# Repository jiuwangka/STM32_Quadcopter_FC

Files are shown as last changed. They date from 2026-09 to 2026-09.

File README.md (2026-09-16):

# STM32 四轴飞行器飞控板 (4-Layer PCB)

基于开源四轴飞行器项目进行硬件方案设计，结合芯片数据手册重新设计飞控板硬件电路，完成原理图绘制、四层PCB设计及硬件调试。

## 我的工作

本人主要负责：

- 飞控板硬件方案设计与器件选型
- 基于芯片数据手册进行外围电路参数设计
- 原理图设计与25×50mm四层PCB设计
- 3.7V→5V→3.3V电源架构设计
- 4路MOSFET电机驱动电路设计
- PCB打样、焊接及硬件调试
- LTspice电机驱动瞬态仿真与电路优化

## 核心硬件架构

- **主控平台**：STM32F103T8U6，72MHz
- **姿态传感**：MPU6050 六轴传感器
- **无线通信**：GC2400-TC017 2.4GHz无线射频模组
- **电源架构**：FP6276BXR-G1 Boost DC-DC（1S锂电池升压至5V）+ TP2019-3.3 LDO（二次降压至3.3V）
- **电机驱动**：4路CJ2310 N-MOSFET驱动716空心杯电机
- **瞬态保护**：1N5819W肖特基续流二极管

## 四层PCB与SI/PI设计

1. **PCB叠层**：L1信号层 - L2连续GND平面 - L3电源层 - L4辅助走线与散热地。
2. **电源与回流设计**：L2采用连续GND平面，为高速及敏感信号提供连续低阻抗回流路径；L3对4路电机采用星型电源分配，减少公共供电路径上的压降及支路间干扰。
3. **射频设计**：GC2400-TC017板载天线区域进行全层铺铜挖空，降低PCB铜箔对2.4GHz射频性能的影响。
4. **瞬态仿真**：提供 `Motor_Drive_Simulation.asc`，通过LTspice分析PWM关断瞬态，加入1N5819W后将仿真中的约500V感应电压尖峰钳位至约4.45V。

## 仓库文件

- `Quadcopter_FC_Hardware_Portfolio_FINAL_V2.1.pdf`：12页硬件设计作品集
- `Gerber.zip`：PCB制造文件
- `BOM.xlsx`：物料清单
- `Pick Place for Quadcopter_FC.csv`：SMT贴装坐标文件
- `Motor_Drive_Simulation.asc`：LTspice电机驱动瞬态仿真
- `Source_Altium/`：Altium Designer工程源码

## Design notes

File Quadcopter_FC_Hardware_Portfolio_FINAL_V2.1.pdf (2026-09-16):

# STM32 Quadcopter Flight Controller (FC) V2.0

# STM32四轴飞行器飞控板系统设计

4-Layer PCB | 4.45V Simulation Result | Hardware Design Portfolio

# HARDWARE DESIGN PORTFOLIO

## PROJECT OVERVIEW · SHEET 01 / 13

系统硬件架构与电源树 / SYSTEM ARCHITECTURE & POWER TREE | 核心参数 / KEY SPECIFICATIONS

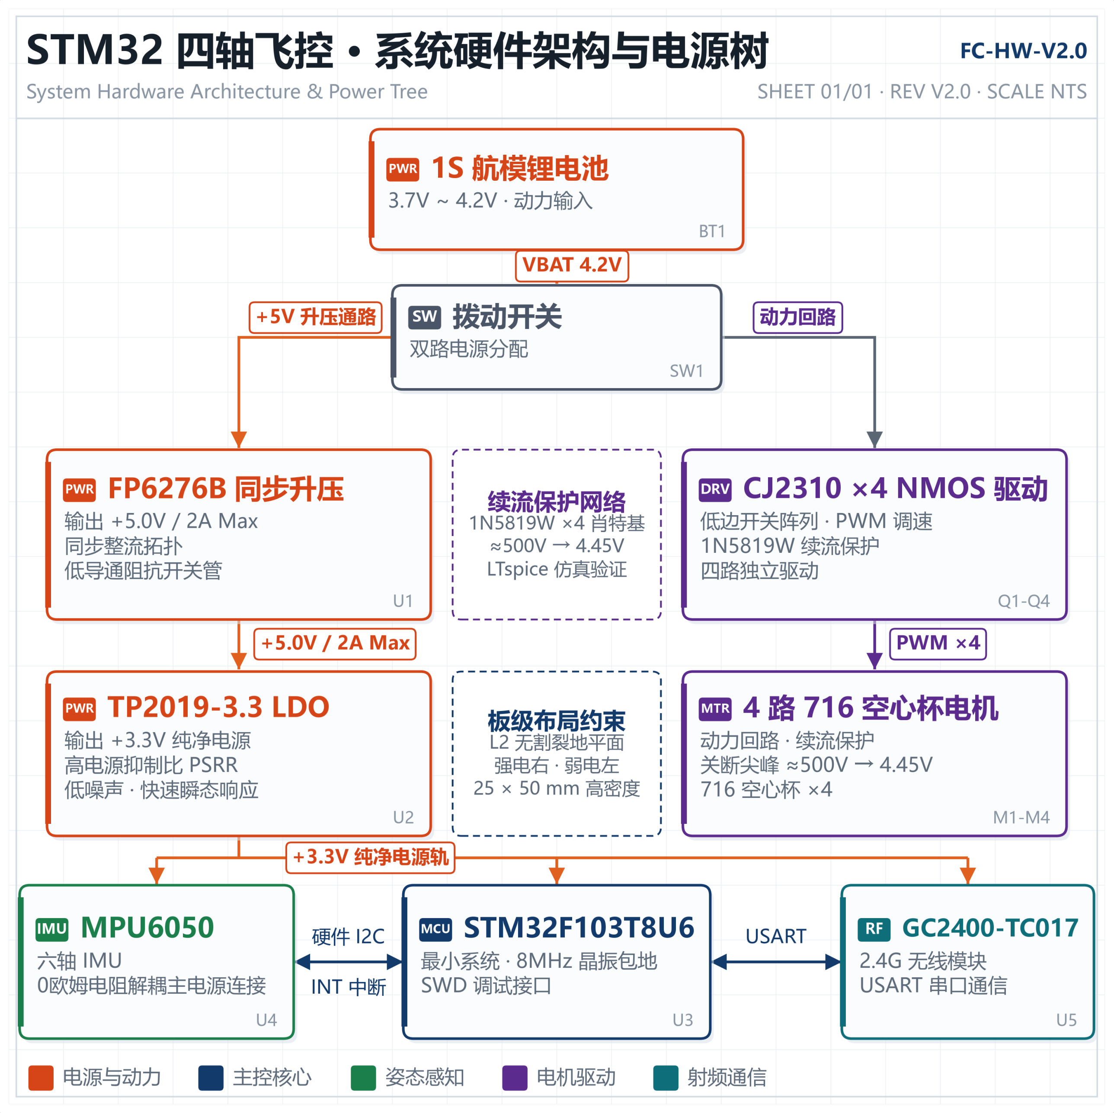
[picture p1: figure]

物理尺寸 | 25mm x 50mm（高密度微型航模规格）
PCB 叠层 | 4层板（Top信号 - L2完整地平面 - L3电源走线 -Bottom底层）
供电架构 | 1S 航模锂电输入 → FP6276B 同步升压 5V → TP2019 高 PSRR LDO 3.3V
动力保护 | 4路 CJ2310 NMOS + 1N5819W 肖特基续流二极管（LTspice 仿真钳位至 4.45V）
传感器与射频 | MPU6050 居中布局，GC2400-TC017 2.4G 板载无线射频模组

## 关键工程要点 / ENGINEERING HIGHLIGHTS

# 完整地回流

# L2 规划为无割裂完整地平面，为电机 PWM 动力回路提供低阻抗返回路径。

# 强弱电隔离

# 强电电机驱动阵列置于板卡右侧，远离左侧弱电 MCU 与 IMU。

# 瞬态钳位仿真

# 建立 716 空心杯电机等效模型，将约 500V 关断感应尖峰钳位至 4.45V。

## 信号链摘要 / SIGNAL CHAIN

## MPU6050

I2C

### STM32F103T8U6

### PWM

CJ2310 ×4

驱动

## 716 空心杯电机

## STM32 Quadcopter FC V2.0 · 微型四轴飞控板系统设计 · 硬件作品集

STM32 Quadcopter Flight Controller (FC) V2.0 | Hardware Portfolio | 01 - 3D Mechanical & Top Assembly View

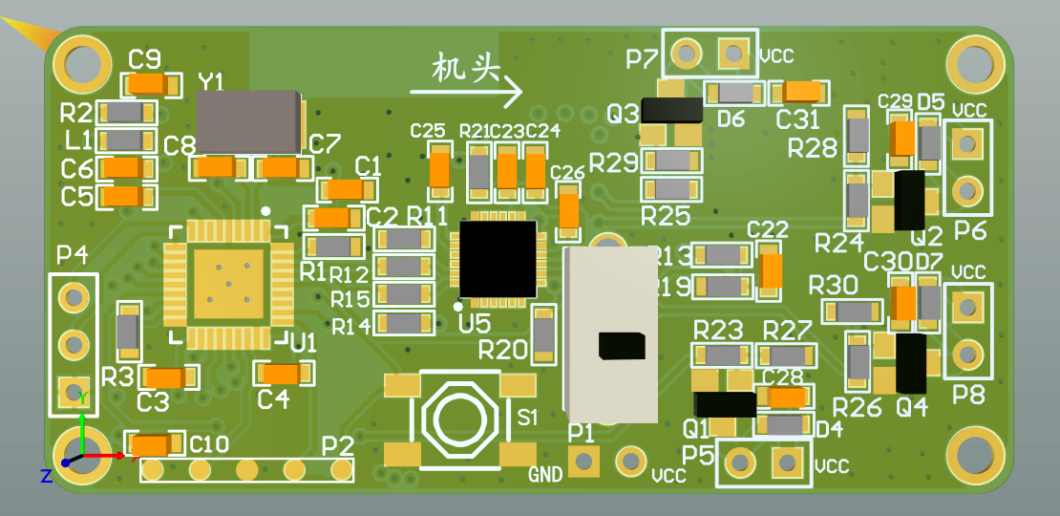
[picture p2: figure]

STM32 Quadcopter Flight Controller (FC) V2.0 | Hardware Portfolio | 01 - 3D Mechanical & Bottom Assembly View

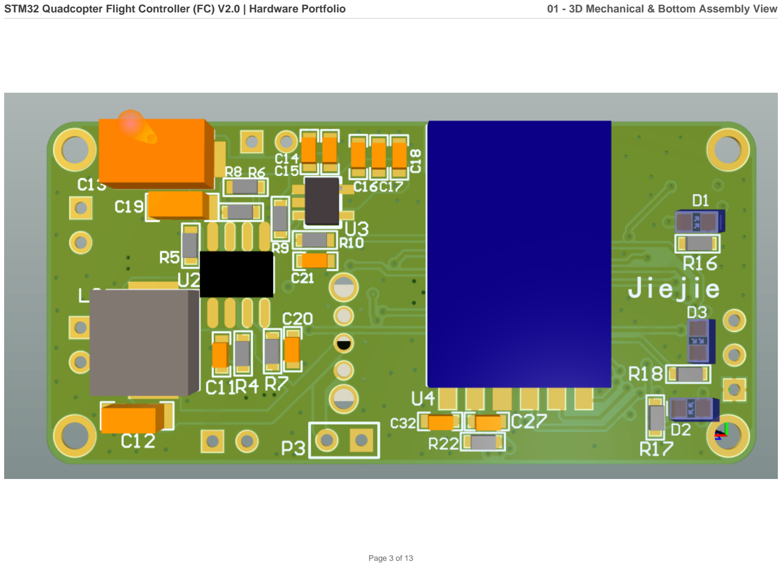
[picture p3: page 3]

## STM32电源区

## STM32功能区

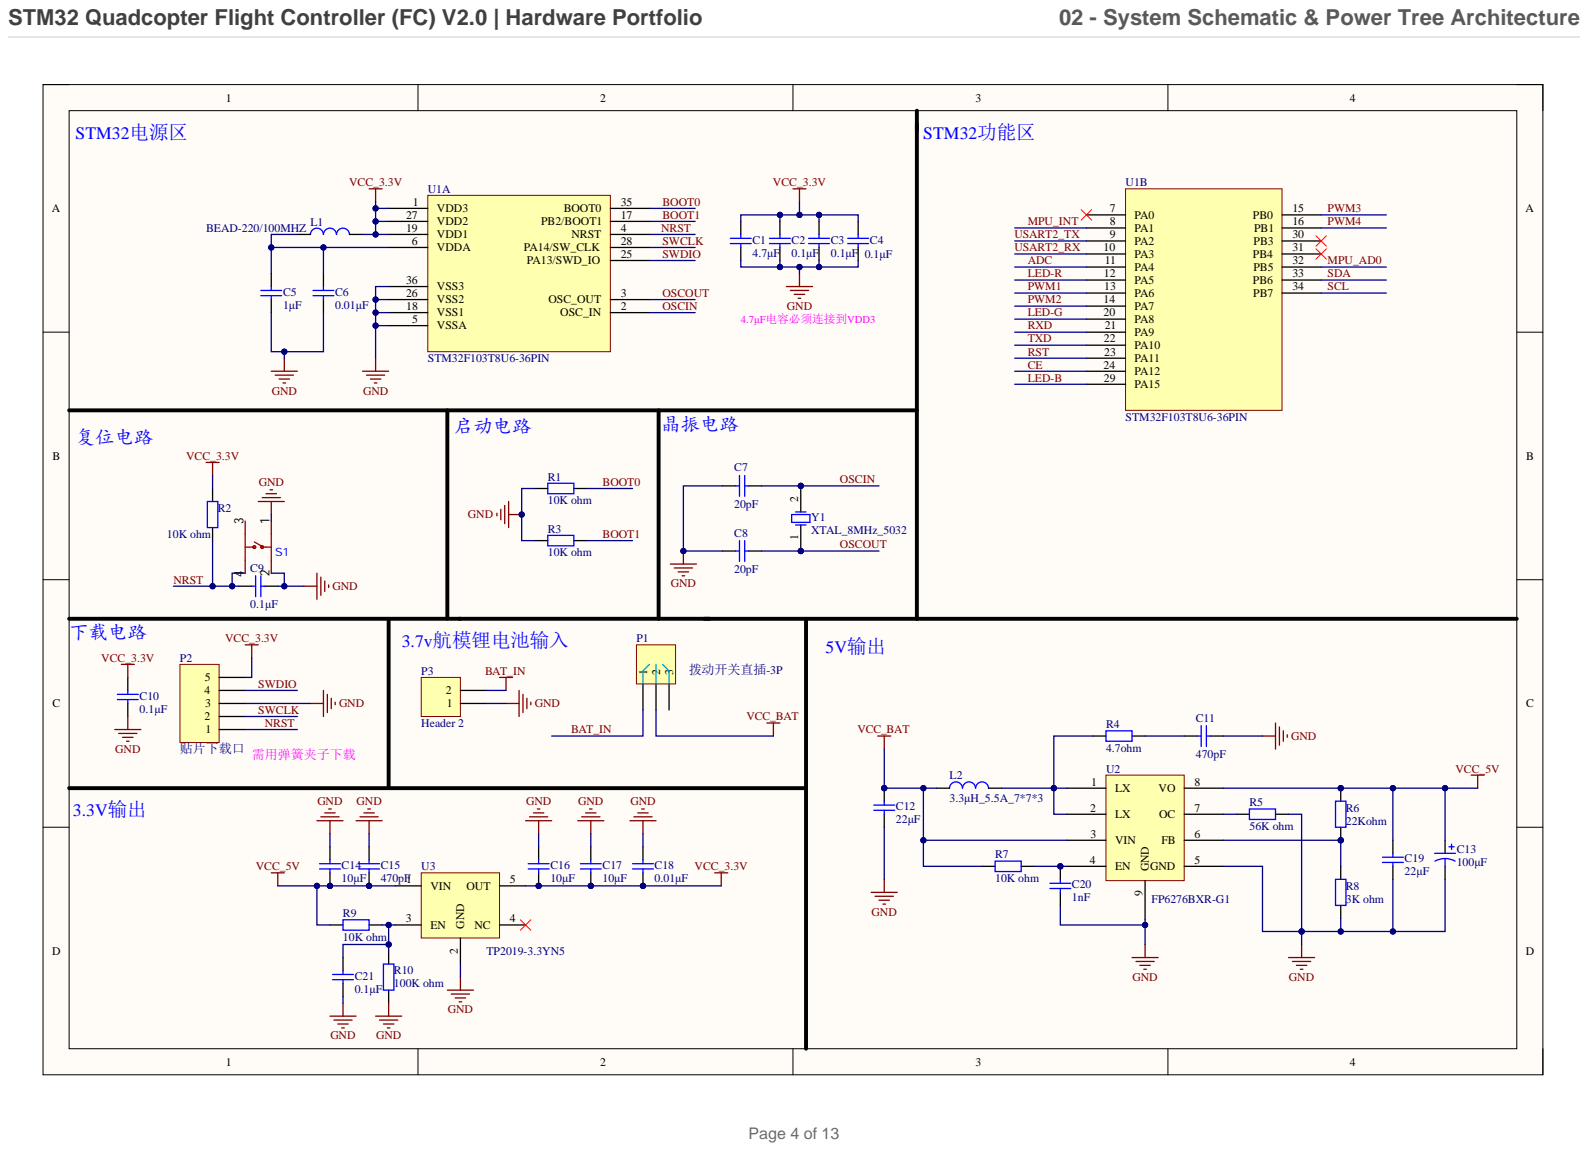
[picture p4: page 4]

# MPU6050

# 电量检测

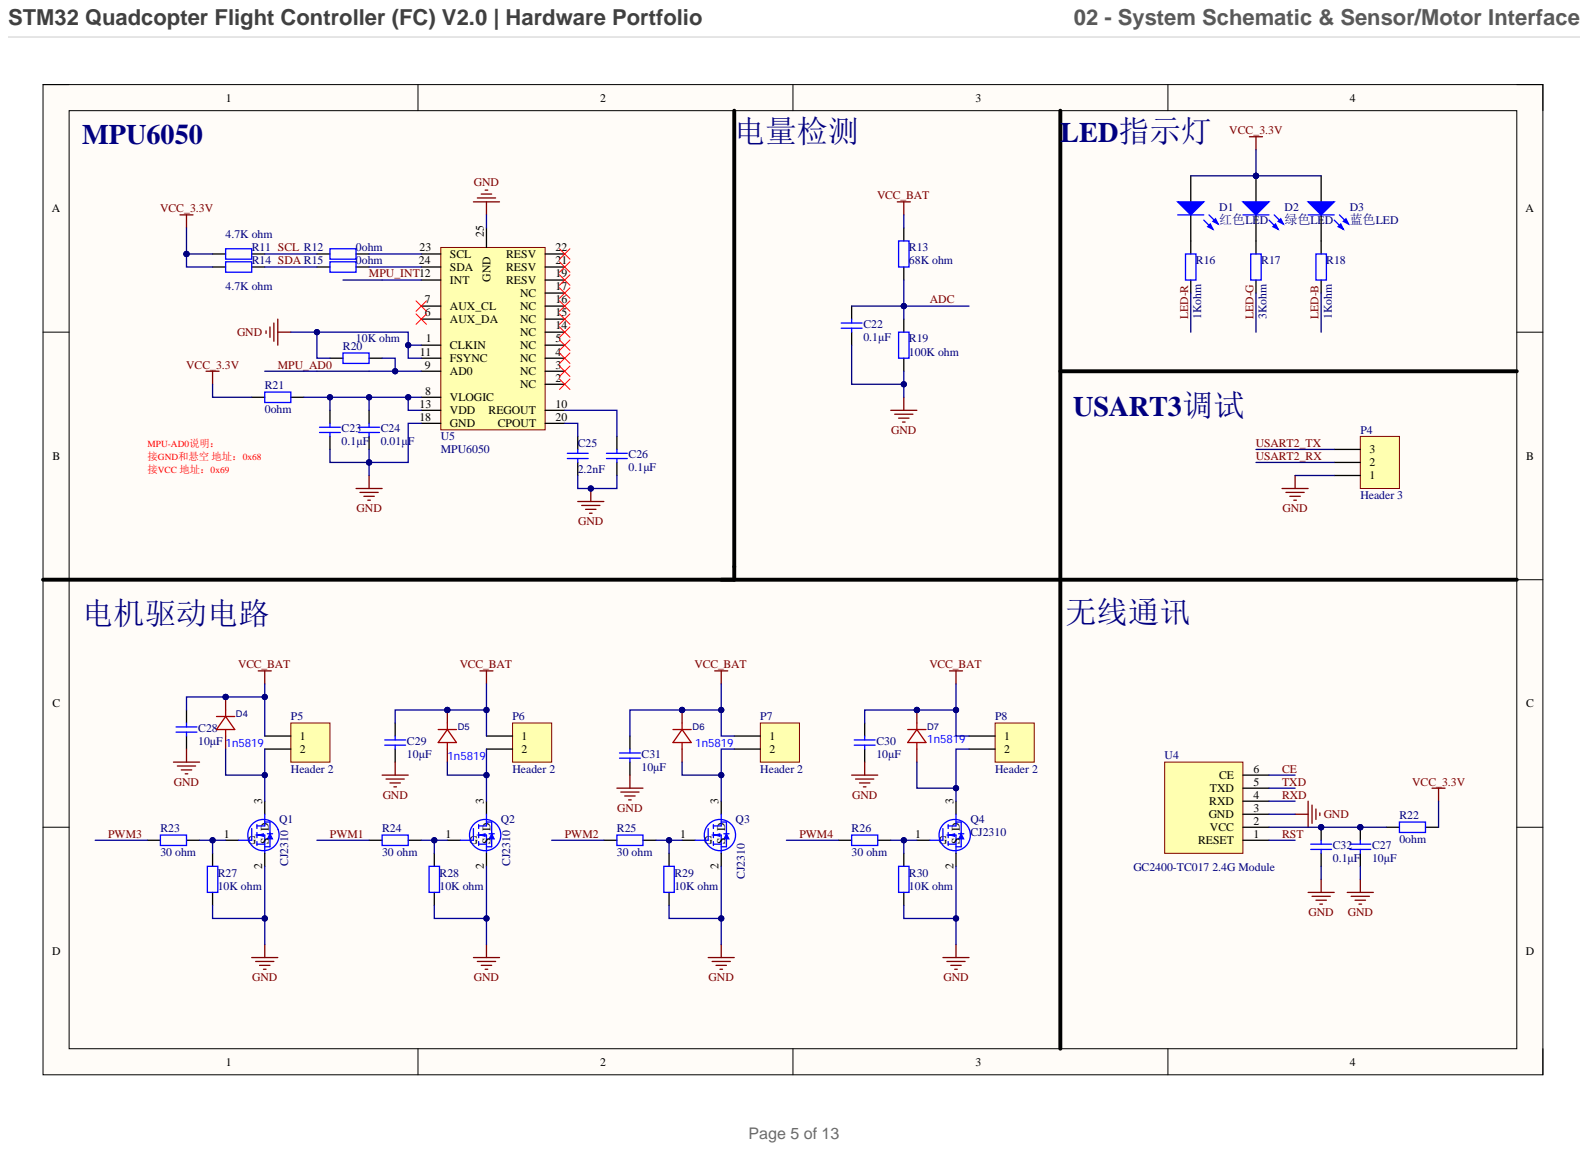
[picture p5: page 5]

STM32 Quadcopter Flight Controller (FC) V2.0 | Hardware Portfolio | 03 - PCB Component Placement & Top Assembly View

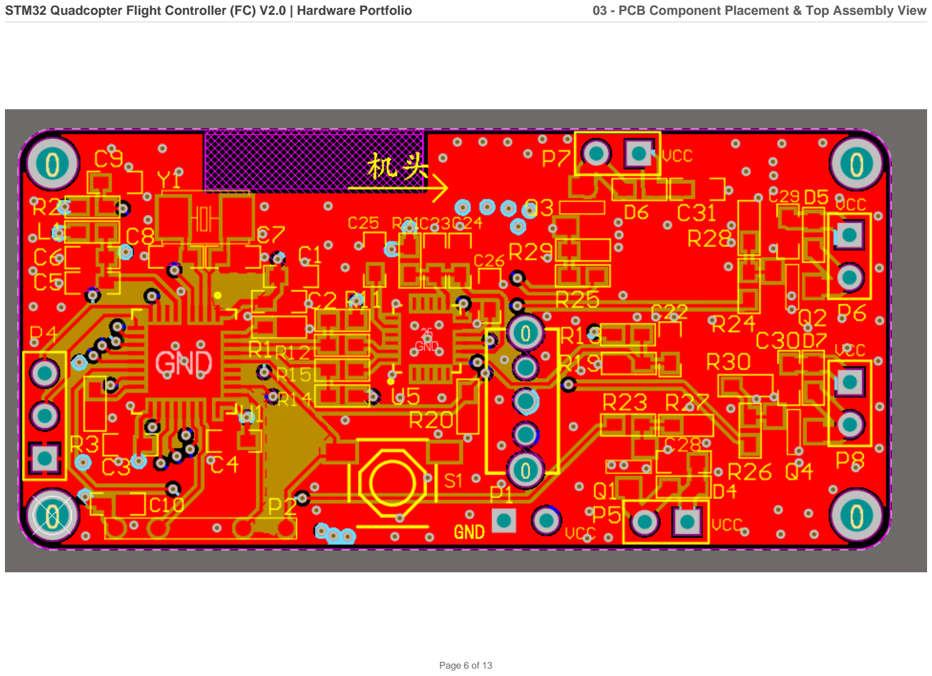
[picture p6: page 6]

STM32 Quadcopter Flight Controller (FC) V2.0 | Hardware Portfolio | 04 - Layer 1 (Top) High-Speed & Signal Routing

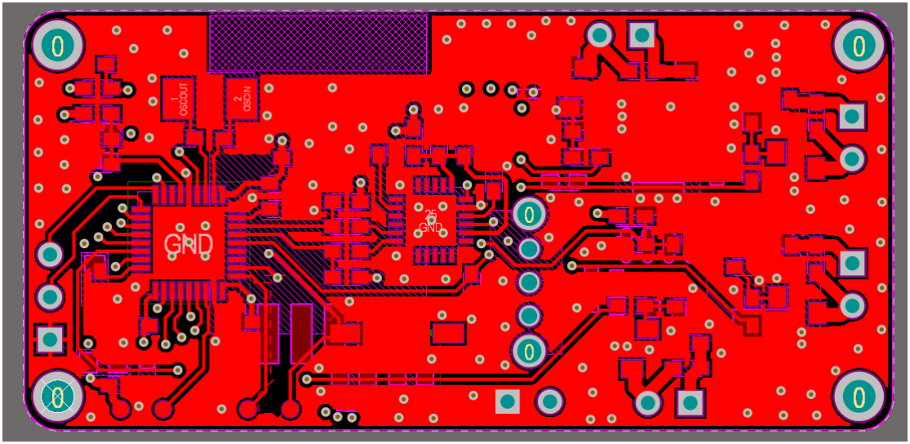
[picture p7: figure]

STM32 Quadcopter Flight Controller (FC) V2.0 | Hardware Portfolio | 04 - Layer 2 (GND) Continuous Ground Plane

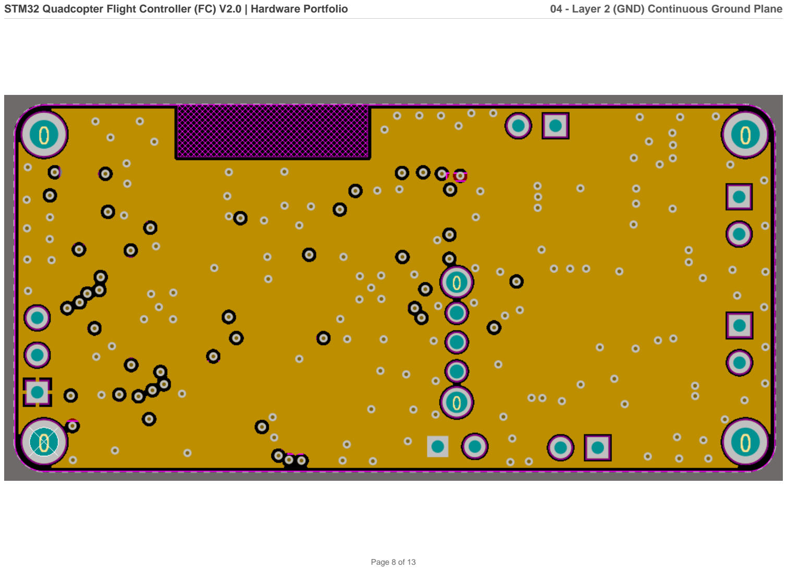
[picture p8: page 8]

STM32 Quadcopter Flight Controller (FC) V2.0 | Hardware Portfolio | 04 - Layer 3 (Power) Battery Power Routing

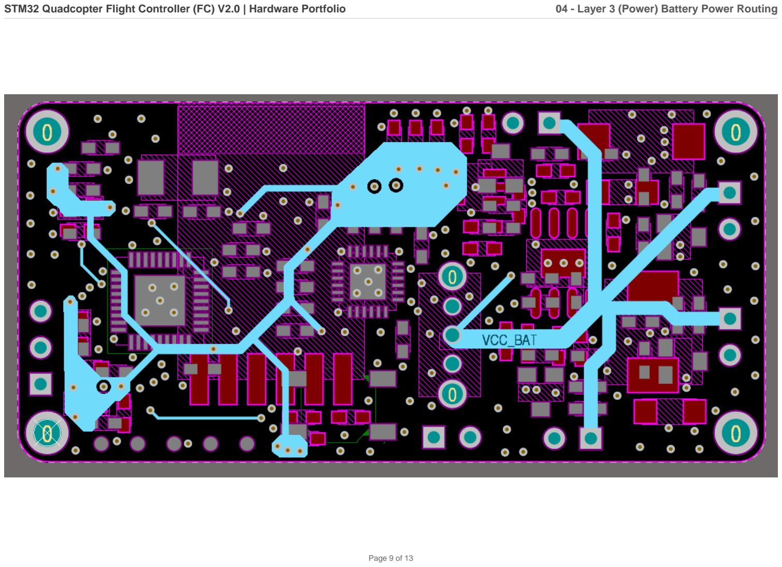
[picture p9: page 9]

STM32 Quadcopter Flight Controller (FC) V2.0 | Hardware Portfolio | 04 - Layer 4 (Bottom) Secondary Routing & Thermal Ground

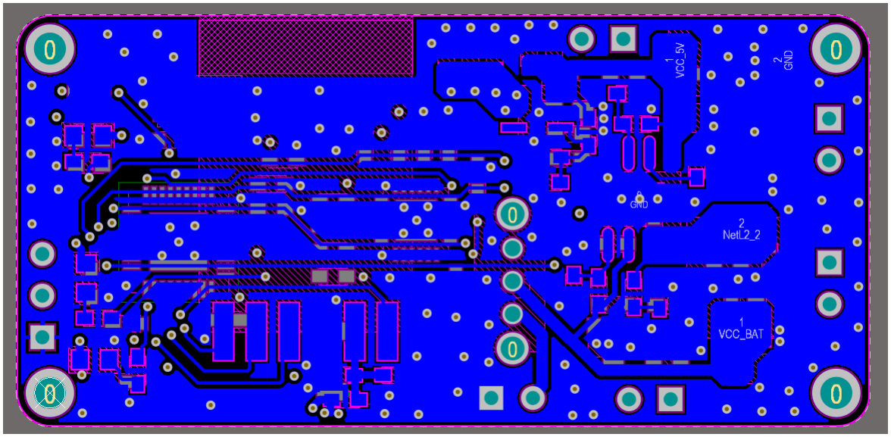
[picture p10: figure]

STM32 Quadcopter Flight Controller (FC) V2.0 | Hardware Portfolio | 05 - Power Rail Ripple Measurement (3.3V Vpp ~ 19.52mV)

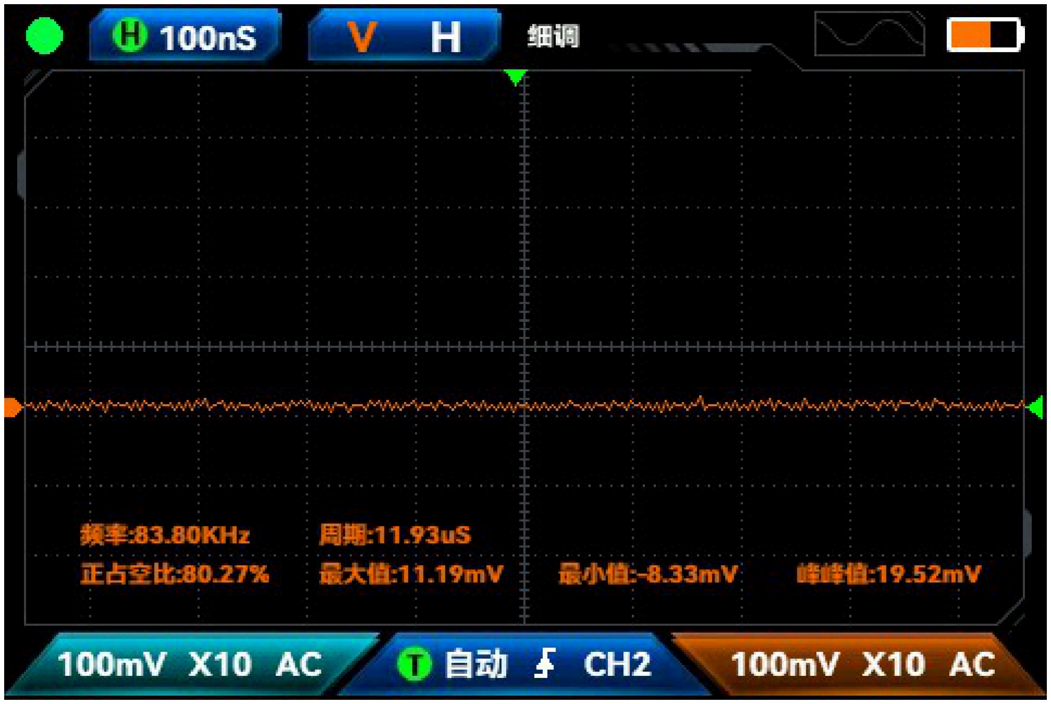
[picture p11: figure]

# 使用FNIRSI DS215H进行板级电源纹波测试，当前测试条件下测得3.3V节点Vpp约19.52mV。

STM32 Quadcopter Flight Controller (FC) V2.0 | Hardware Portfolio | 06 - Flyback Suppression Simulation (No Diode: ~500V Spike)

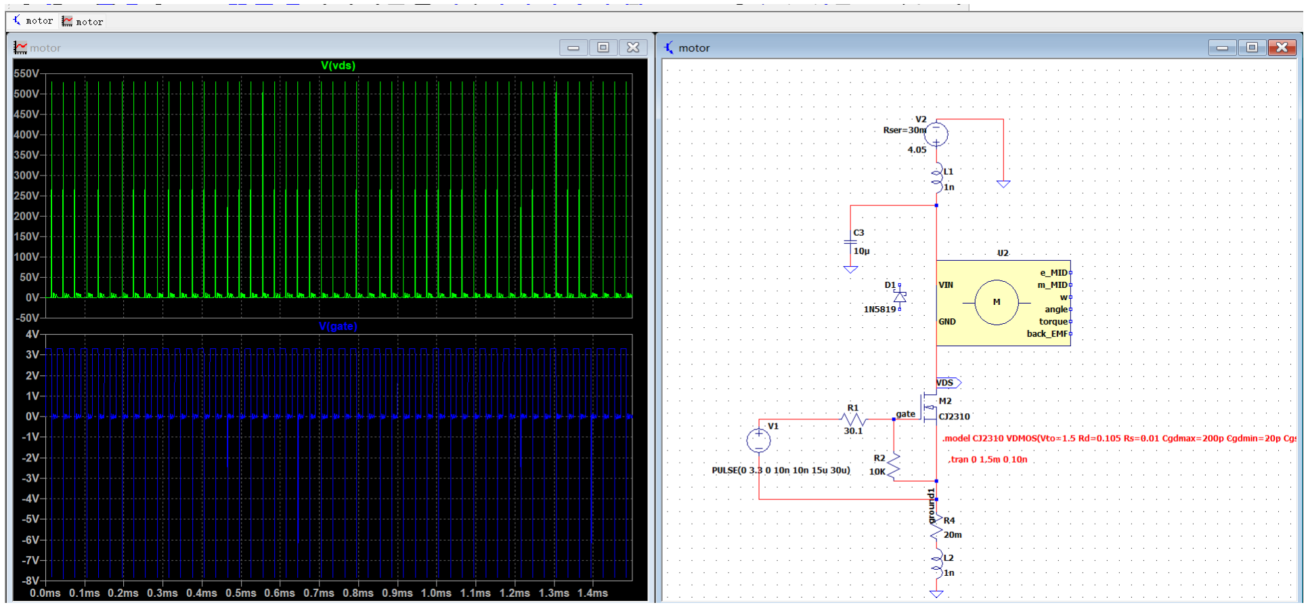
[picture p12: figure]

# CONCLUSION · 结论对比 - LTspice 瞬态仿真结果

条件 / CONDITION | 峰值电压 / VDS PEAK | 说明 / NOTE
Without Flyback Diode | VDS peak | 500 V | MOSFET 关断瞬间产生高幅值感应尖峰
With 1N5819W | VDS peak | 4.45 V | 续流路径建立，关断尖峰得到有效钳位

STM32 Quadcopter Flight Controller (FC) V2.0 | Hardware Portfolio | 06 - Flyback Suppression Simulation (Clamped: 4.45V Simulation Result)

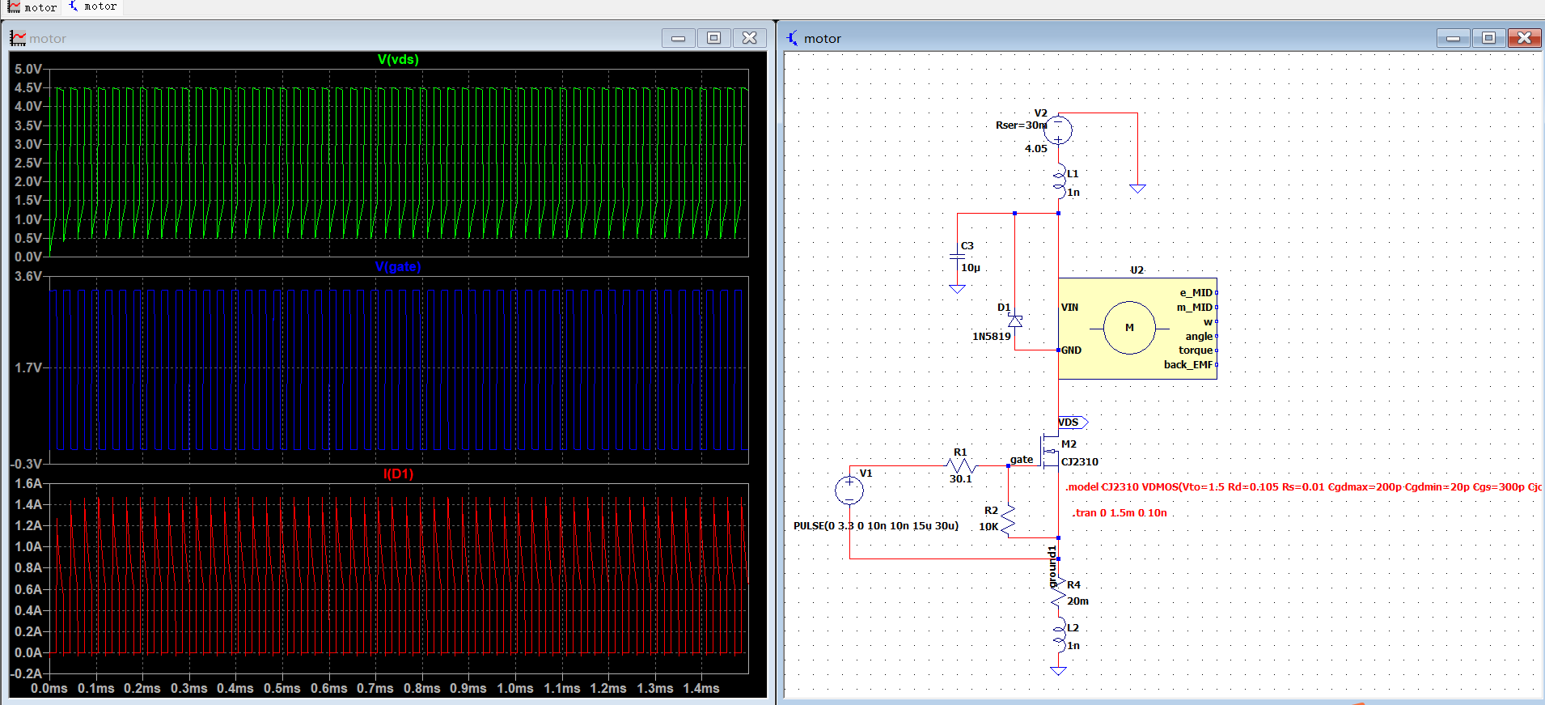
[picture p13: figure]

# CONCLUSION · 结论对比 - LTspice 瞬态仿真结果

条件 / CONDITION | 峰值电压 / VDS PEAK | 说明 / NOTE
Without Flyback Diode | VDS peak | 500 V | MOSFET 关断瞬间产生高幅值感应尖峰
With 1N5819W | VDS peak | 4.45 V | 续流路径建立，关断尖峰得到有效钳位

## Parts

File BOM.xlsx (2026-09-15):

Comment | Description | Designator | Footprint | LibRef | Quantity
4.7μF | 0.1μF_50V,X7R,±5% | C1 | 0603C | Cap_0.1μF_50V_0603 | 1
0.1μF | 0.1μF_50V,X7R,±5%, 1μF_50V,X5R,±10% | C2, C3, C4, C9, C10, C21, C22, C23, C26, C32 | 0603C | Cap_0.1μF_50V_0603, Cap_1μF_50V_0603 | 10
1μF | 0.1μF_50V,X7R,±5% | C5 | 0603C | Cap_0.1μF_50V_0603 | 1
0.01μF | 0.1μF_50V,X7R,±5% | C6, C18, C24 | 0603C | Cap_0.1μF_50V_0603 | 3
20pF | 20pF_50V,CH,±5% | C7, C8 | 0603C | Cap_20pF_50V_0603 | 2
470pF | 2.2nF_50V,X7R,10%, 1μF_50V,X5R,±10% | C11, C15 | 0603C | Cap_2.2nF_50V_0603, Cap_1μF_50V_0603 | 2
22μF | 22μF_35V,20% | C12, C19 | 1206C | Cap_22μF_35V_1206 | 2
100μF | 100μF_16V | C13 | D7343C | Cap_100μF_16V_D7343 | 1
10μF | 1μF_50V,X5R,±10%, 10μF_35V,X5R,20%, 4.7μF_50V,±10% | C14, C16, C17, C27, C28, C29, C30, C31 | 0603C | Cap_1μF_50V_0603, Cap_10μF_35V_0603, Cap_4.7μF_50V_0603 | 8
1nF | 1μF_50V,X5R,±10% | C20 | 0603C | Cap_1μF_50V_0603 | 1
2.2nF | 10μF_35V,X5R,20% | C25 | 0603C | Cap_10μF_35V_0603 | 1
红色LED | 蓝色LED | D1 | 0603LED | 蓝色LED | 1
绿色LED | 蓝色LED | D2 | 0603LED | 蓝色LED | 1
蓝色LED | 蓝色LED | D3 | 0603LED | 蓝色LED | 1
1n5819 | 二极管配置:独立式;正向压降(Vf):600mV@200mA;直流反向耐压(Vr):40V;整流电流:350mA; | D4, D5, D6, D7 | 0603R | 1n5819wt_c5451630 | 4
BEAD-220/100MHZ | BEAD-220/100MHZ | L1 | 0603R | BEAD-220/100MHZ_0603 | 1
3.3μH_5.5A_7*7*3 | 4.7μH_5.5A_ | L2 | 7*7*3mm - 06030 | 4.7μH_5.5A_7*7*3 | 1
拨动开关直插-3P | 拨动开关直插-3P | P1 | Switch-3P | 拨动开关直插-3P | 1
贴片下载口 | 微型下载口 | P2 | download | 微型下载口 | 1
Header 2 | Header, 2-Pin | P3, P5, P6, P7, P8 | HDR1X2 | Header 2 | 5
Header 3 | Header, 3-Pin | P4 | HDR1X3 | Header 3 | 1
CJ2310 | CJ2310 | Q1, Q2, Q3, Q4 | SOT23-3 | CJ2310 | 4
10K ohm | 10K ohm,1% | R1, R2, R3, R7, R9, R20, R27, R28, R29, R30 | 0603R | Res_10K ohm_0603 | 10
4.7ohm | 24K ohm,1% | R4 | 0603R | Res_24K ohm_0603 | 1
56K ohm | 30K ohm,1% | R5 | 0603R | Res_30K ohm_0603 | 1
22Kohm | 100K ohm_5% | R6 | 0603R | Res_100Kohm_0603 | 1
3K ohm | 13K ohm,1% | R8 | 0603R | Res_13K ohm_0603 | 1
100K ohm | 10K ohm,1%, 68K ohm,1% | R10, R19 | 0603R | Res_10K ohm_0603, Res_68K ohm_0603 | 2
4.7K ohm | 4.7K ohm,1% | R11, R14 | 0603R | Res_4.7K ohm_0603 | 2
0ohm | 120 ohm_5%, 24K ohm,1% | R12, R15, R21, R22 | 0603R | Res_120ohm_0603, Res_24K ohm_0603 | 4
68K ohm | 200K ohm,1% | R13 | 0603R | Res_200K ohm_0603 | 1
1Kohm | 510 ohm,1% | R16, R18 | 0603R | Res_510ohm_0603 | 2
3Kohm | 510 ohm,1% | R17 | 0603R | Res_510ohm_0603 | 1
30 ohm | 100 ohm_5% | R23, R24, R25, R26 | 0603R | Res_100ohm_0603 | 4
BX-TS-26-4416TT |  | S1 | SW-SMD_4P-L5.2-W5.2-P3.70-LS6.5 | BX-TS-26-4416TT | 1
STM32F103T8U6-36PIN |  | U1 | QFN-36N | STM32F103T8U6-36PIN | 1
FP6276BXR-G1 | FP6277 | U2 | SO8 - FP6277 | FP6277 | 1
TP2019-3.3YN5 | TP2019-3.3YN5 | U3 | SOT-23-5 | TP2019-3.3YN5 | 1
GC2400-TC017 2.4G Module | 2.4G_转串口 | U4 | 2.4G-Serial port | 2.4G_转串口 | 1
MPU6050 | MPU6050 | U5 | QFN24 | MPU6050 | 1
XTAL_8MHz_5032 | XTAL_8MHz | Y1 | 5032 | XTAL_8MHz_5032 | 1
